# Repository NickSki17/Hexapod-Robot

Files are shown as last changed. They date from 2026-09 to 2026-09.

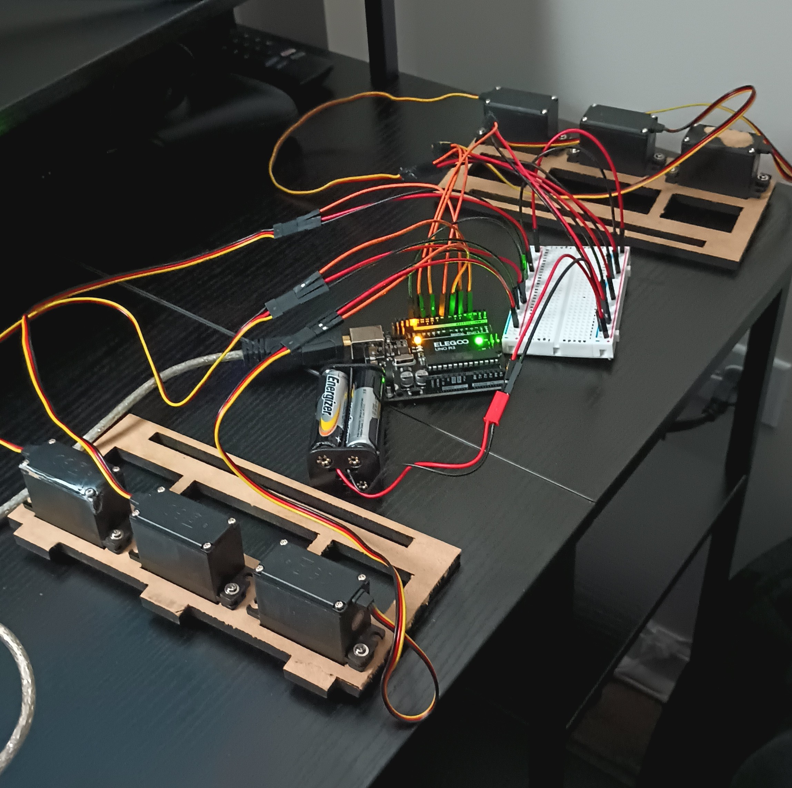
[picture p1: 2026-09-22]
Media/hexapod_wiring.jpg

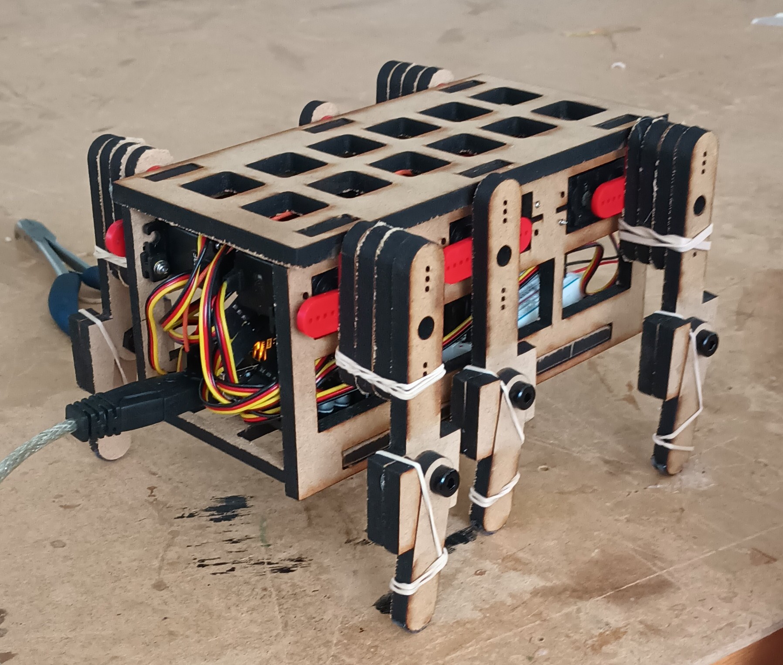
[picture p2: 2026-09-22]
Media/hexapod_front.jpg

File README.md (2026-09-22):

# Hexapod Tripod Gait Robot

A six-legged, ant-inspired robot developed around an alternating tripod gait, passive lower-leg mechanisms, and six servo-driven actuated joints. The project combines concept selection, Inventor CAD, preliminary actuator sizing, Arduino firmware, fabrication, and a physical walking demonstration.

**Tools:** Autodesk Inventor, Arduino C++, `Servo.h`, MDF fabrication

## Project Overview

| **Feature** | **Specification / Detail** | **Evidence Class**  |
| :--- | :--- | :--- |
| **Architecture** | 6-legged hexapod with tripod gait | Designed |
| **Microcontroller** | Arduino Uno | Physical Prototype  |
| **Actuators** | 6 × Hitec HS-425BB standard servos | Physical Prototype  |
| **Chassis Material** | 1/4″ (6.35 mm) MDF | Physical Prototype  |
| **Degrees of Freedom** | 6 total (1 actuated DOF per leg) | Designed |
| **Knee Joints** | Passive mechanical stops (~7.5°) with elastic assist | Designed / Physical |
| **Walking Speed** | Not measured in this repository | Unverified |
| **Power Supply** | 6 V battery pack | Physical Prototype  |

The robot uses six legs arranged into two alternating tripod groups. Each leg features one servo-driven shoulder joint paired with a passive lower-leg mechanism. During stance, a mechanical stop makes the lower leg act as a rigid support member. During swing, the lower linkage folds forward to reduce toe dragging before returning via elastic assist.

### Concept Selection

The hexapod design was selected over an inchworm-inspired alternative based on preliminary design trade-offs:

* **Static Stability:** Provides a three-point support polygon during each tripod phase without requiring active balancing.
* **Mechanical Simplicity:** Uses single-DOF active joints with passive compliant knees to reduce mechanical and control complexity.

## Mechanical Design & Fabrication

The physical robot is constructed from 1/4″ (6.35 mm) MDF for the main chassis, upper legs, and lower legs, with six Hitec HS-425BB servos controlled by an Arduino Uno.

* **Leg Geometry:** Upper leg length: ~60 mm | Lower leg length: 40 mm
* **Body Offset:** Legs offset 26 mm from chassis centerline
* **Knee Joints:** Passive mechanical stops limiting forward rotation to ~7.5°, with elastic return assist
* **Traction:** Rubber toe grips

## Engineering Sizing & Analysis

The preliminary design calculations evaluated the static torque demands on the shoulder servos under simplified load conditions.

| **Parameter** | **Value** | **Evidence Class**  | **Notes / Source** |
| :--- | :--- | :--- | :--- |
| **Calculated Robot Mass** | 0.69 kg | Calculated | Sum of chassis, servos, battery, and leg components |
| **Total Weight ($W$)** | 6.77 N | Calculated | Derived from $0.69\text{ kg} \times 9.81\text{ m/s}^2$ |
| **Assumed Leg Load ($F_{leg}$)** | 3.38 N | Assumed | Load assumption used in original sizing calculation |
| **Required Torque ($T_{req}$)**  | 0.203 N·m (2.07 kgf·cm) | Calculated | Static moment arm check at 60 mm |
| **Servo Stall Torque** | 4.10 kgf·cm | Specified | Hitec HS-425BB datasheet rating at 6 V |
| **Static Factor of Safety** | ~1.98 | Preliminary theoretical calculation | Ratio of rated/stall torque to required static torque under the documented simplified load assumption |
| **Walking Speed** | 0.24 m/s (1.3 BL/s) | Reported benchmark  | Instructor-evaluated physical benchmark |

> **Analysis Note:** Equal static load sharing across an ideal 3-leg tripod stance yields ~2.26 N per leg ($6.77\text{ N}/3$). The 3.38 N value was retained from the original sizing calculation as the documented design load assumption. The ~1.98 factor of safety is therefore a preliminary/theoretical static calculation based on that assumption and the servo's rated/stall torque; it is not an experimentally validated operating margin. These calculations do not model dynamic acceleration, joint friction, or voltage drop under load.

## Control System & Firmware

The control software is implemented in Arduino C++ using the standard `Servo.h` library.

### Servo Pin Assignment

| **Servo Leg Position** | **Arduino Pin** | **Neutral Position** | **Target Stance Angle** |
| :--- | :--- | :--- | :--- |
| **Left Front (LF)** | Pin 2 | 90° | 70° |
| **Left Middle (LM)** | Pin 4 | 90° | 110° |
| **Left Rear (LR)** | Pin 7 | 90° | 68° |
| **Right Front (RF)** | Pin 8 | 90° | 70° |
| **Right Middle (RM)**  | Pin 10 | 90° | 110° |
| **Right Rear (RR)** | Pin 12 | 90° | 67° |

### Gait Execution

1. **Startup:** Attaches all six servos and smoothly transitions from 90° neutral to the initial gait position over 1000 ms.
2. **Stance Hold:** Holds the initial position for 7000 ms.
3. **Tripod Gait:** Alternates between two tripod groups:

   * **Tripod A:** LF, RM, LR
   * **Tripod B:** RF, LM, RR
4. **Smooth Interpolation:** Uses 25 sub-steps over a nominal 225 ms phase to coordinate servo motion.

The current control system is **open-loop** and does not use position feedback or closed-loop gait control.

## Physical Prototype & Media

The physical robot was fabricated, wired, and tested as a walking prototype.

* [Front Profile View](Media/hexapod_front.jpg)
* [Rear Profile View](Media/hexapod_rear.jpg)
* [Chassis & Servo Layout](Media/hexapod_body.jpg)
* [Arduino & Power Wiring](Media/hexapod_wiring.jpg)
* [Walking Video Demonstration](Media/hexapod_walking_demo.mp4)

## Documentation & CAD

* [Arduino Firmware](Code/hexapod_controller.ino)
* [Engineering / Design Analysis](Documentation/hexapod_design_analysis.pdf)
* [Mechanical Drawings](Documentation/hexapod_engineering_drawings.pdf)
* [Inventor Assembly](CAD/hexapod_assembly.iam)
* [Inventor Presentation](CAD/hexapod_presentation.ipn)
* [Inventor Parts](CAD/CAD%20Parts/)

## Limitations & Future Work

* **Open-Loop Control:** No ground-contact, IMU, or position feedback is currently implemented.
* **Dynamic Torque Modeling:** The actuator sizing uses a simplified static moment-arm calculation and does not model dynamic leg loading.
* **Gait Optimization:** Stride amplitude and timing are currently fixed firmware parameters.
* **Quantitative Testing:** The repository does not include an independently documented walking-speed measurement, distance testing, physical mass measurement, or servo calibration data. The 0.24 m/s value in the analysis table is an instructor-evaluated benchmark reported by the project documentation.
* **Firmware Notes:** The gait uses fixed angle, timing, and interpolation parameters; no feedback or automatic gait adaptation is implemented.

## Repository Structure

```text
Hexapod-Robot/
├── README.md
├── .gitignore
├── Code/
│   └── hexapod_controller.ino
├── CAD/
│   ├── hexapod_assembly.iam
│   ├── hexapod_presentation.ipn
│   ├── CAD Parts/
│   └── OldVersions/
├── Documentation/
│   ├── hexapod_design_analysis.pdf
│   └── hexapod_engineering_drawings.pdf
└── Media/
    ├── hexapod_front.jpg
    ├── hexapod_rear.jpg
    ├── hexapod_body.jpg
    ├── hexapod_wiring.jpg
    └── hexapod_walking_demo.mp4
```

## Tools & Skills

**Autodesk Inventor · Arduino C++ · Servo Control · Tripod Gait · Mechanism Design · Actuator Sizing · Static Torque Analysis · CAD · MDF Fabrication · Physical Prototyping**

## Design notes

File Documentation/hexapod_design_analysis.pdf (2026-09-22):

Ant Inspired: Six legs arranged into two groups of three legs to act as a stable tripod. On servo drive each leg. It has a tripod gait where the bottom linkage of the leg is freely moving. When a leg is on the ground pushing, the knee stop locks the shin in place, creating a rigid leg that propels the robot forward. When the leg lifts off the ground, the shin freely folds forward, allowing the leg to swing back compactly through the air without dragging.

Inchworm Inspired: Two body segments that are connected by an extension mechanism. To push forward, the rear anchor will activate, and the front will deactivate. The servo will rotate causing an extension from a crank-rocker linkage. Then the anchors will switch, and the rear will be pulled forward.

I chose the hexapod (ant-inspired) because it offers the best balance of speed, performance, and reliability. The tripod gait provides static stability as there are three legs always supporting the robot, making it unlikely to tip over. Additionally, the hexapod has a potential for higher speed, so it can compete for bonus points. While it requires six servos compared to the inchworms two, the torque analysis confirms the servos have enough torque to move the weight. The bio inspiration is simple and using the crank-rocker linkages as the legs are likely to be successful. Although it requires more servos, the hexapod is the better choice due to its stability and speed.

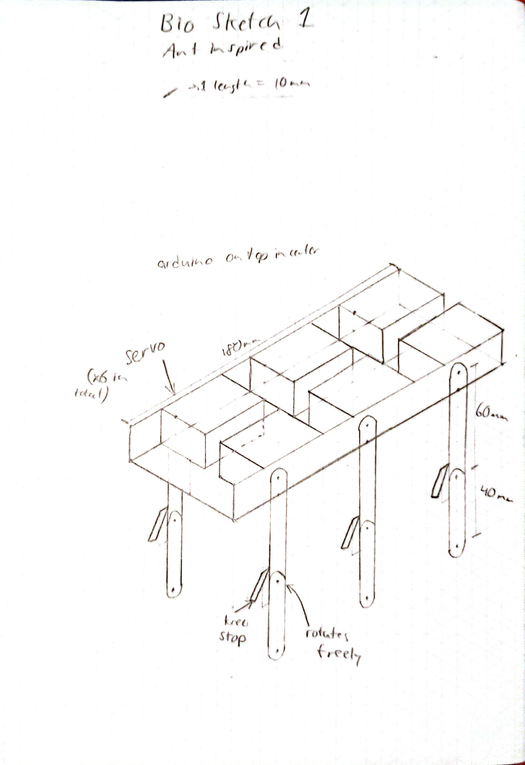
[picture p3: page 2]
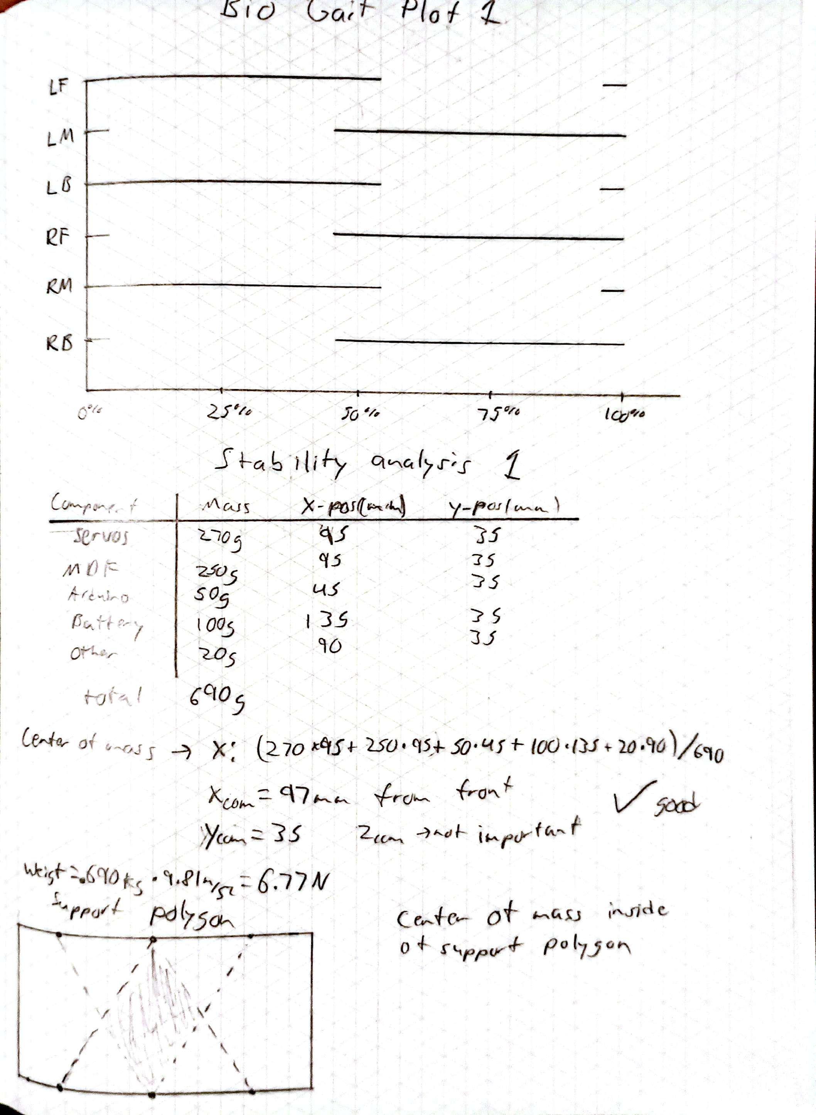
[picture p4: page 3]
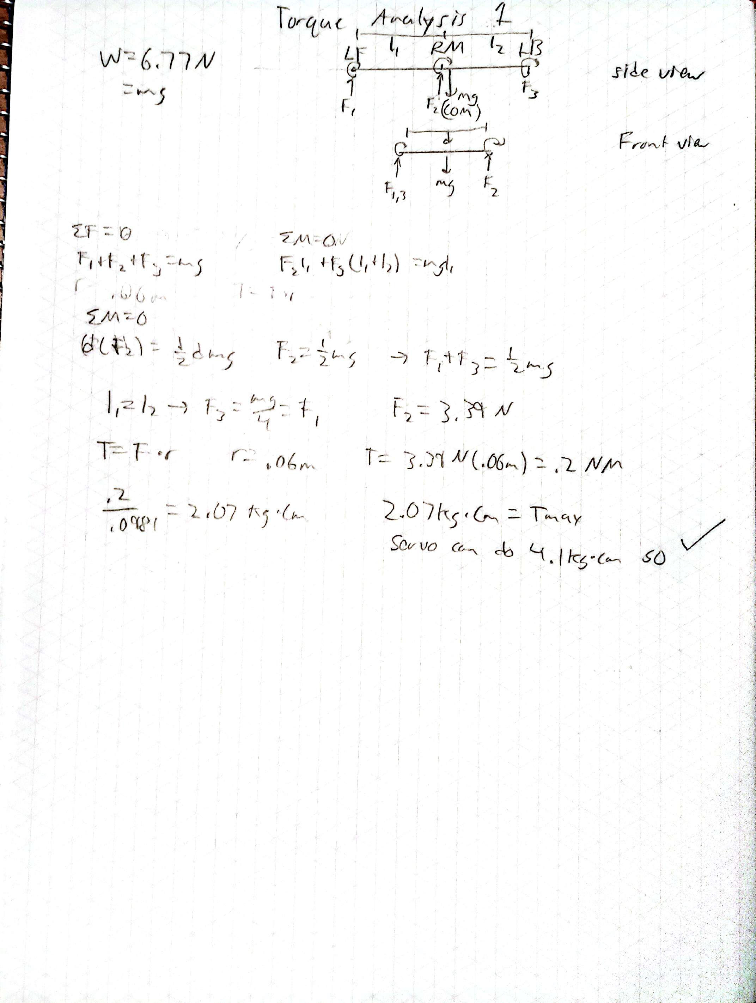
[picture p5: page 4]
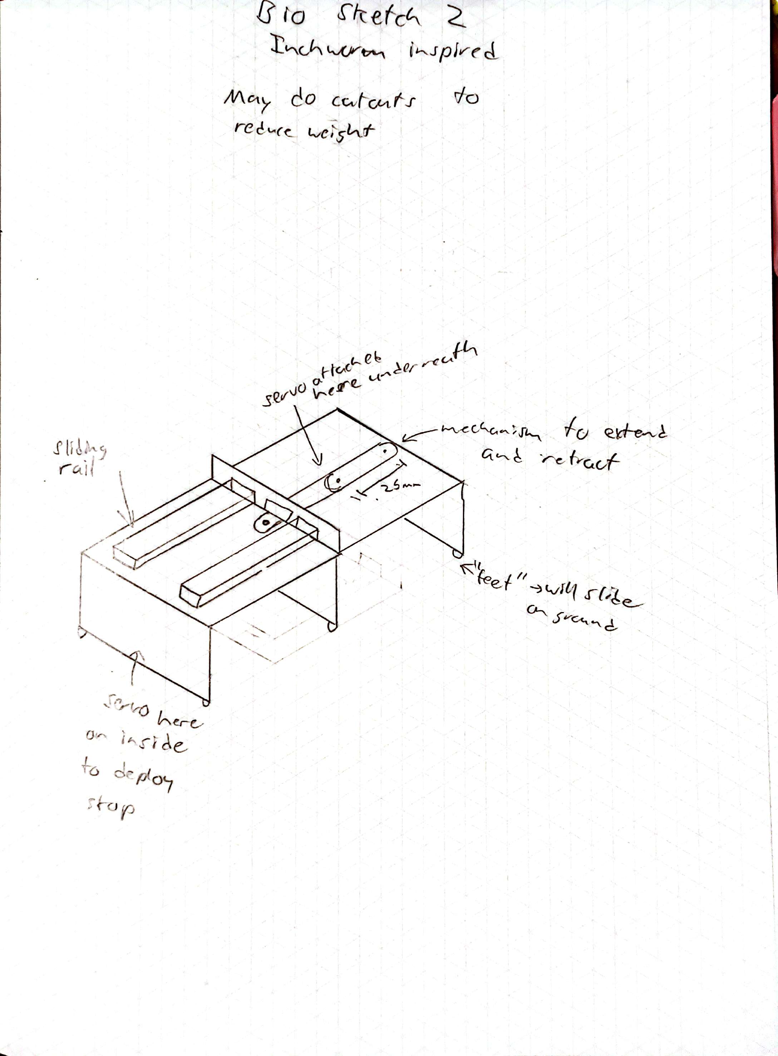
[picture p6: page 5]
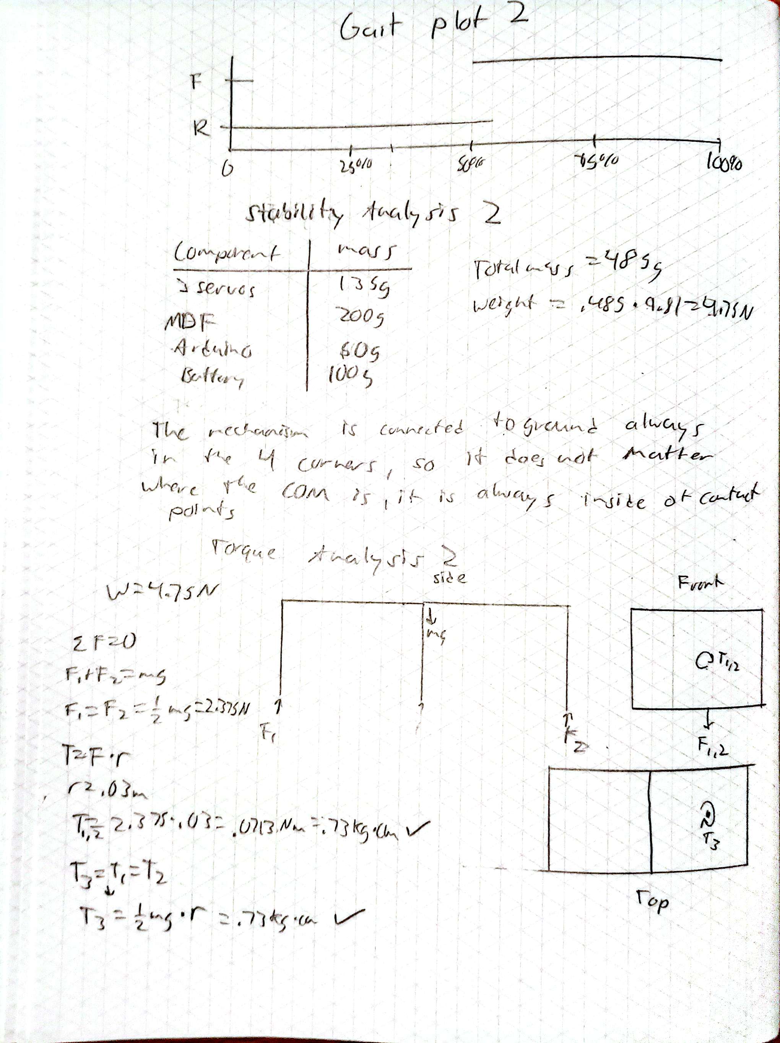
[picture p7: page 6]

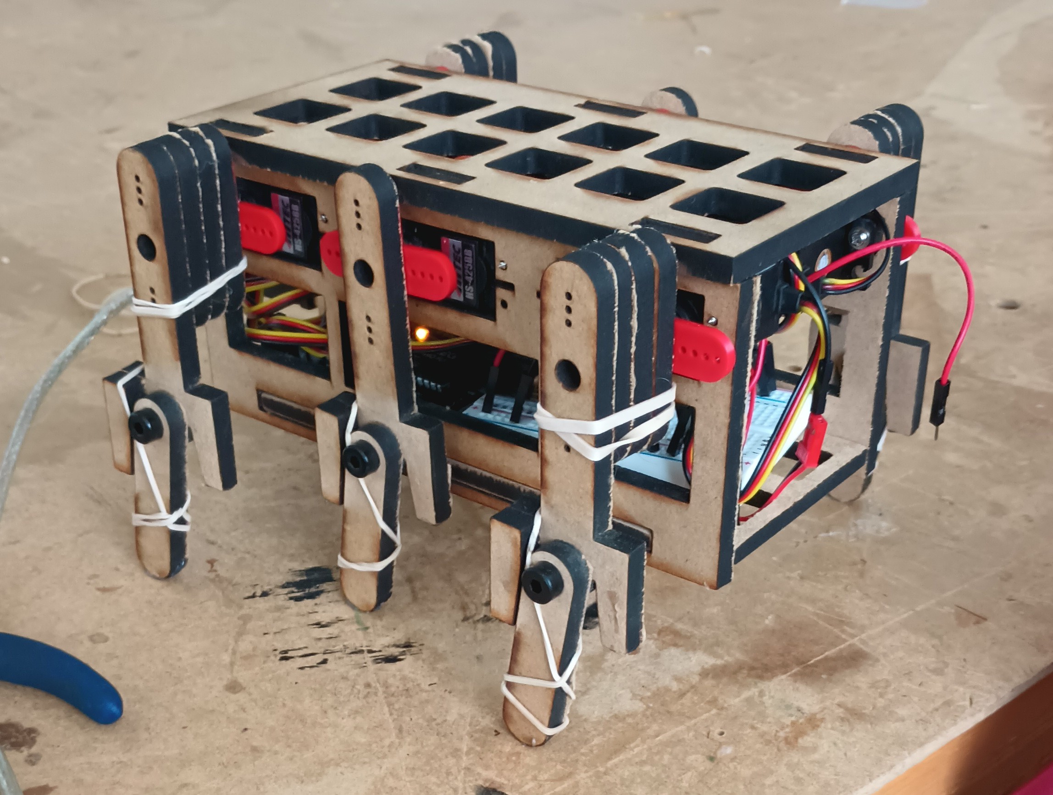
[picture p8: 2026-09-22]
Media/hexapod_rear.jpg

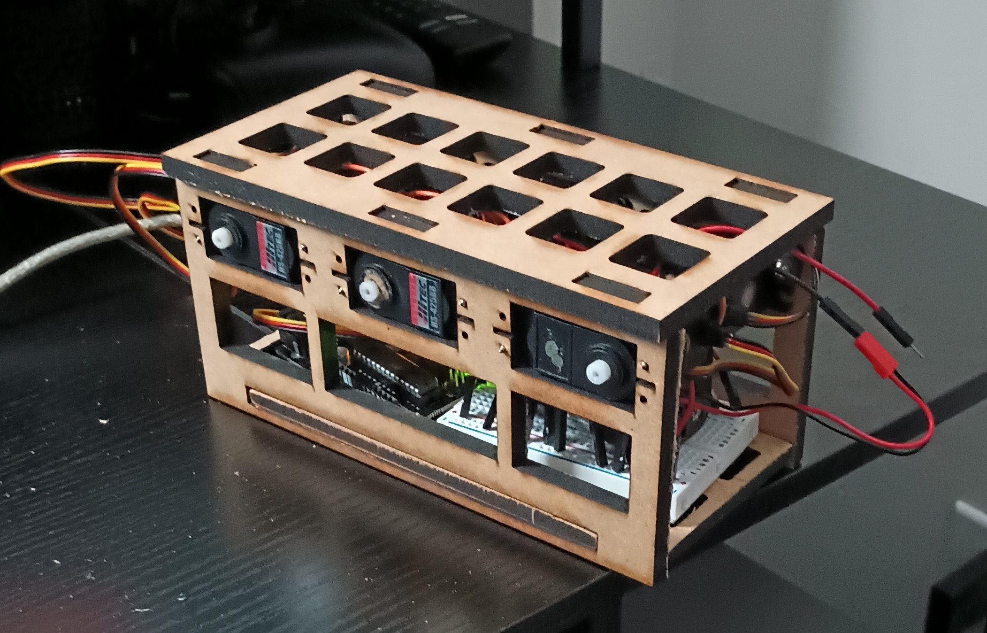
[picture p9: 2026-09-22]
Media/hexapod_body.jpg

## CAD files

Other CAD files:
CAD/CAD Parts/93897A255_Nylon Shoulder Screws (Short Screw) Skiba.ipt
CAD/CAD Parts/Base-Skiba.ipt
CAD/CAD Parts/Bio Servo Skiba.ipt
CAD/CAD Parts/Bio Servo Skiba_MIR1.ipt
CAD/CAD Parts/Lower Leg Skiba.ipt
CAD/CAD Parts/OldVersions/93897A255_Nylon Shoulder Screws (Short Screw) Skiba.0002.ipt
CAD/CAD Parts/OldVersions/Base-Skiba.0007.ipt
CAD/CAD Parts/OldVersions/Bio Servo Skiba.0001.ipt
CAD/CAD Parts/OldVersions/Bio Servo Skiba_MIR1.0002.ipt
CAD/CAD Parts/OldVersions/Lower Leg Skiba.0005.ipt
CAD/CAD Parts/OldVersions/Roof Skiba.0002.ipt
CAD/CAD Parts/OldVersions/Servo Holder Skiba.0001.ipt
CAD/CAD Parts/OldVersions/Servo Horn Skiba.0002.ipt
CAD/CAD Parts/OldVersions/Servo Wall Skiba.0005.ipt
CAD/CAD Parts/OldVersions/Servo Wall Skiba_MIR1.0002.ipt
CAD/CAD Parts/OldVersions/Spacer Skiba.0005.ipt
CAD/CAD Parts/OldVersions/Stop Skiba.0005.ipt
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

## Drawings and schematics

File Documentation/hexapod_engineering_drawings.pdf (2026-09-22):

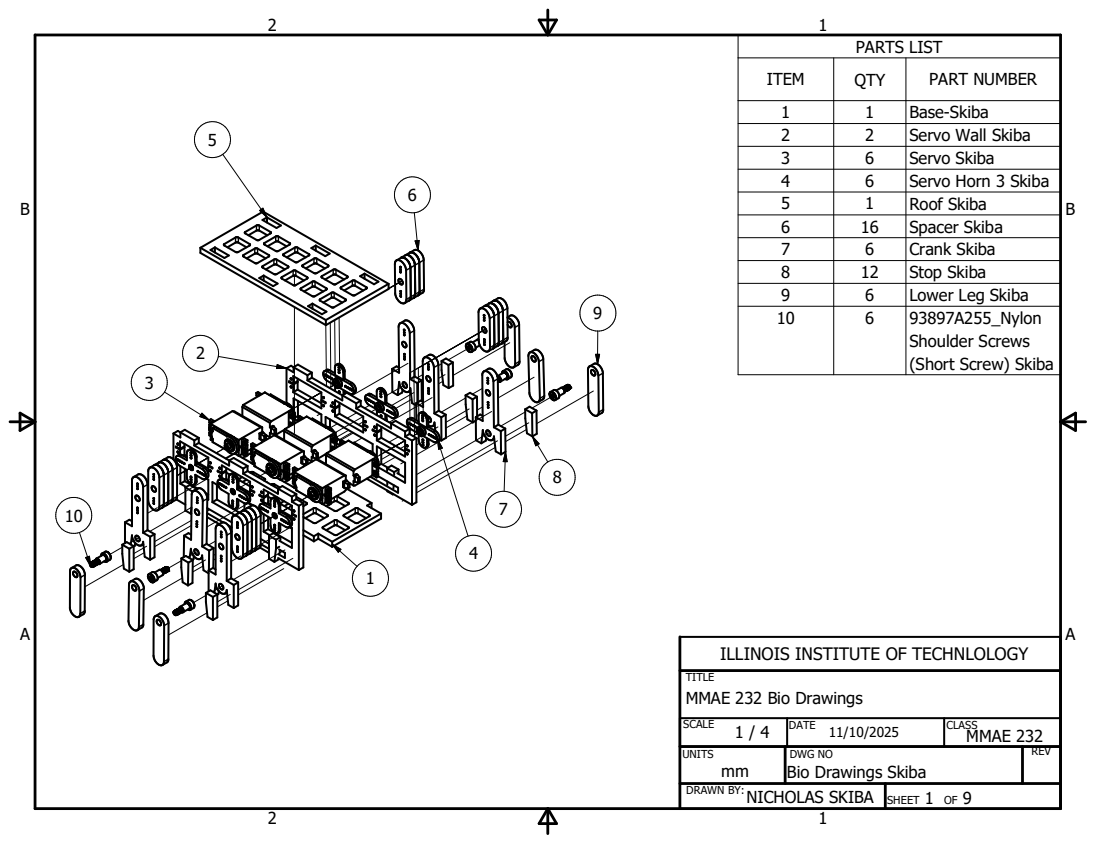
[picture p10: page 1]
REV; SCALE; 1 / 4 DATE; CLASS; MMAE 232; UNITS; DWG NO; PARTS LIST; ITEM; QTY; PART NUMBER; Base-Skiba; Servo Wall Skiba; Servo Skiba; Servo Horn 3 Skiba; Roof Skiba; Spacer Skiba; Crank Skiba; Stop Skiba; Lower Leg Skiba

93897A255_Nylon
Shoulder Screws
(Short Screw) Skiba

ILLINOIS INSTITUTE OF TECHNLOLOGY

TITLE
MMAE 232 Bio Drawings

SHEET 1 OF 9 DRAWN BY:NICHOLAS SKIBA

Bio Drawings Skiba

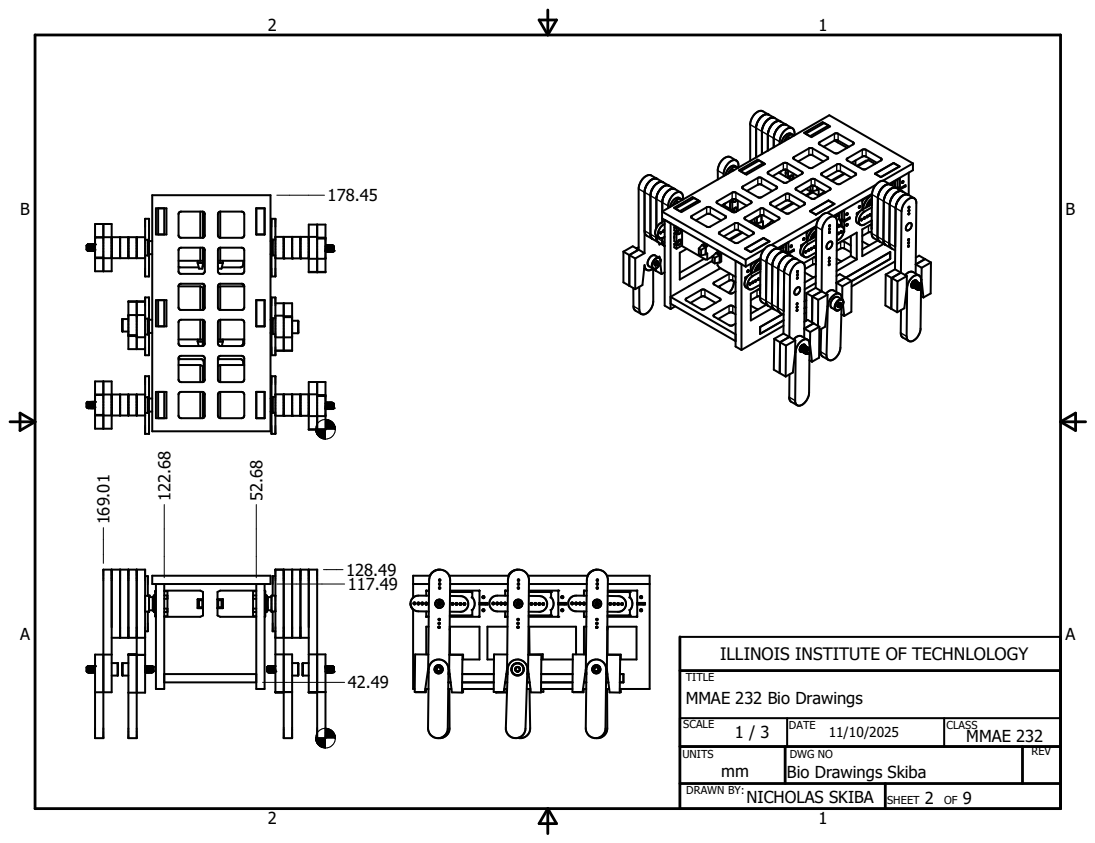
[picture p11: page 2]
REV; SCALE; 1 / 3 DATE; CLASS; MMAE 232; UNITS; DWG NO; 117.49 ¹²².68; 128.49 ¹⁶⁹.01

ILLINOIS INSTITUTE OF TECHNLOLOGY

TITLE
MMAE 232 Bio Drawings

SHEET 2 OF 9 DRAWN BY:NICHOLAS SKIBA

Bio Drawings Skiba

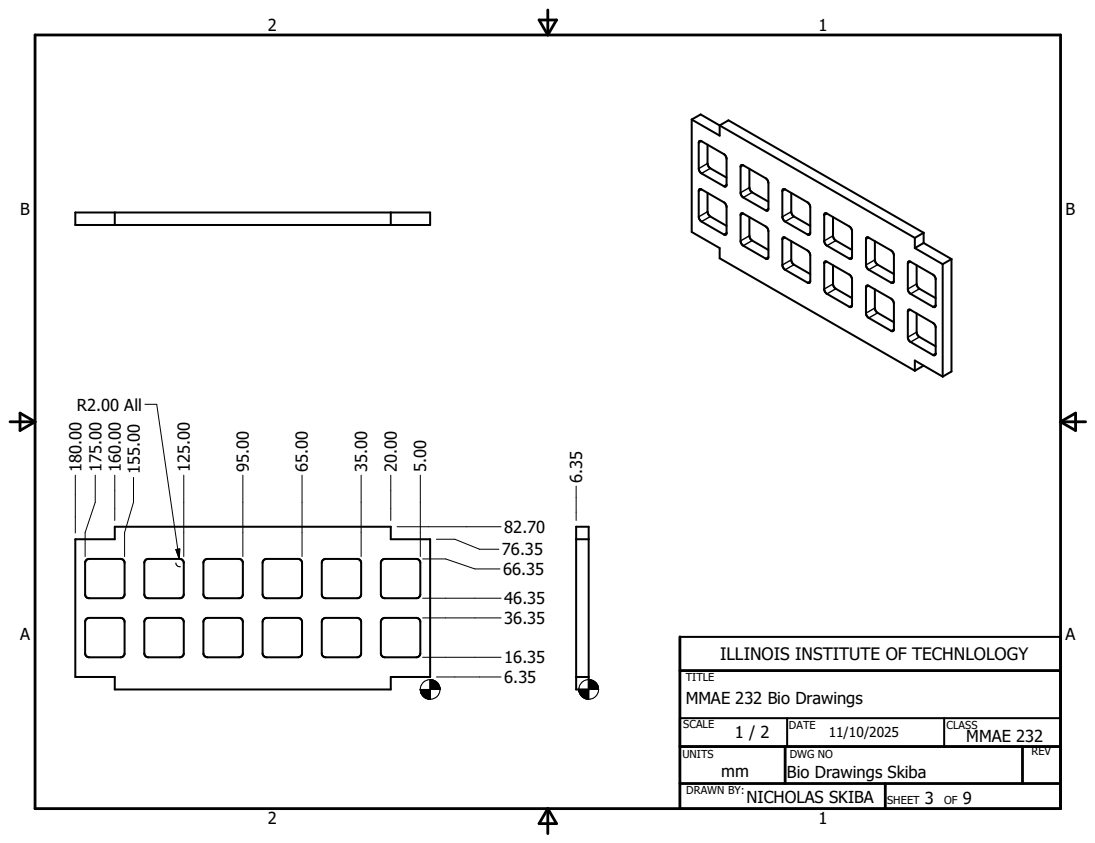
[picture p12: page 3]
82.70 ¹⁸⁰.00 175.00 160.00 155.00; R2.00 All

ILLINOIS INSTITUTE OF TECHNLOLOGY

TITLE
MMAE 232 Bio Drawings

SCALE 1 / 2 | DATE 11/10/2025 | CLASS MMAE 232
UNITS mm | DWG NO Bio Drawings Skiba | REV

SHEET 3 OF 9 DRAWN BY:NICHOLAS SKIBA

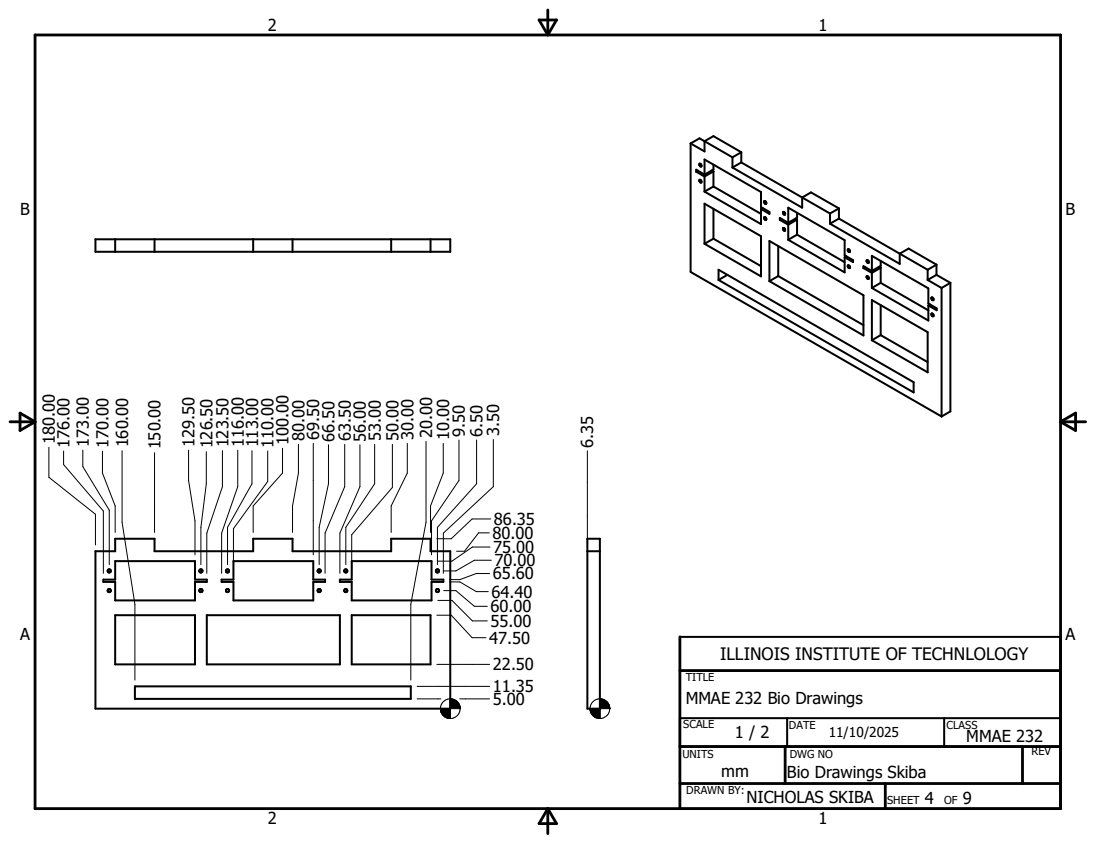
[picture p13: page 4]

ILLINOIS INSTITUTE OF TECHNLOLOGY

TITLE
MMAE 232 Bio Drawings

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

SHEET 4 OF 9 DRAWN BY:NICHOLAS SKIBA

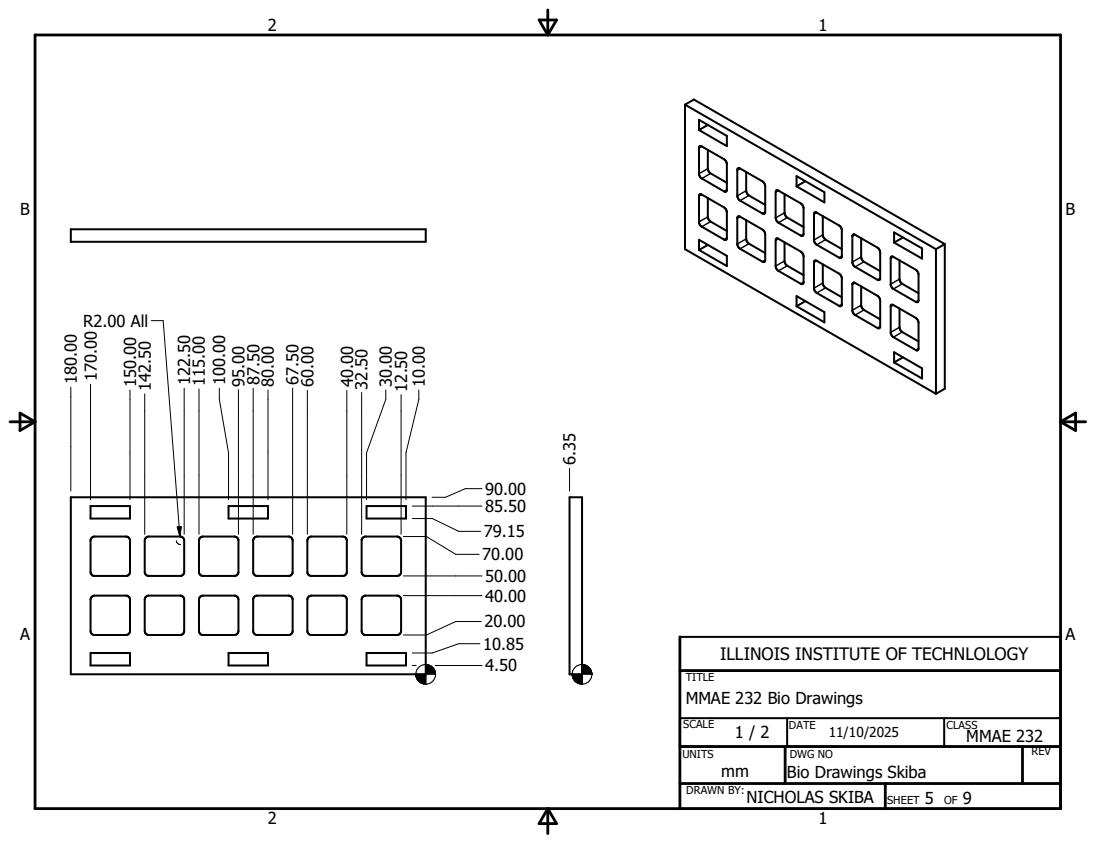
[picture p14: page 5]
R2.00 All

ILLINOIS INSTITUTE OF TECHNLOLOGY

TITLE
MMAE 232 Bio Drawings

SCALE 1 / 2 | DATE 11/10/2025 | CLASS MMAE 232
UNITS | DWG NO Bio Drawings Skiba | REV

SHEET 5 OF 9 DRAWN BY:NICHOLAS SKIBA

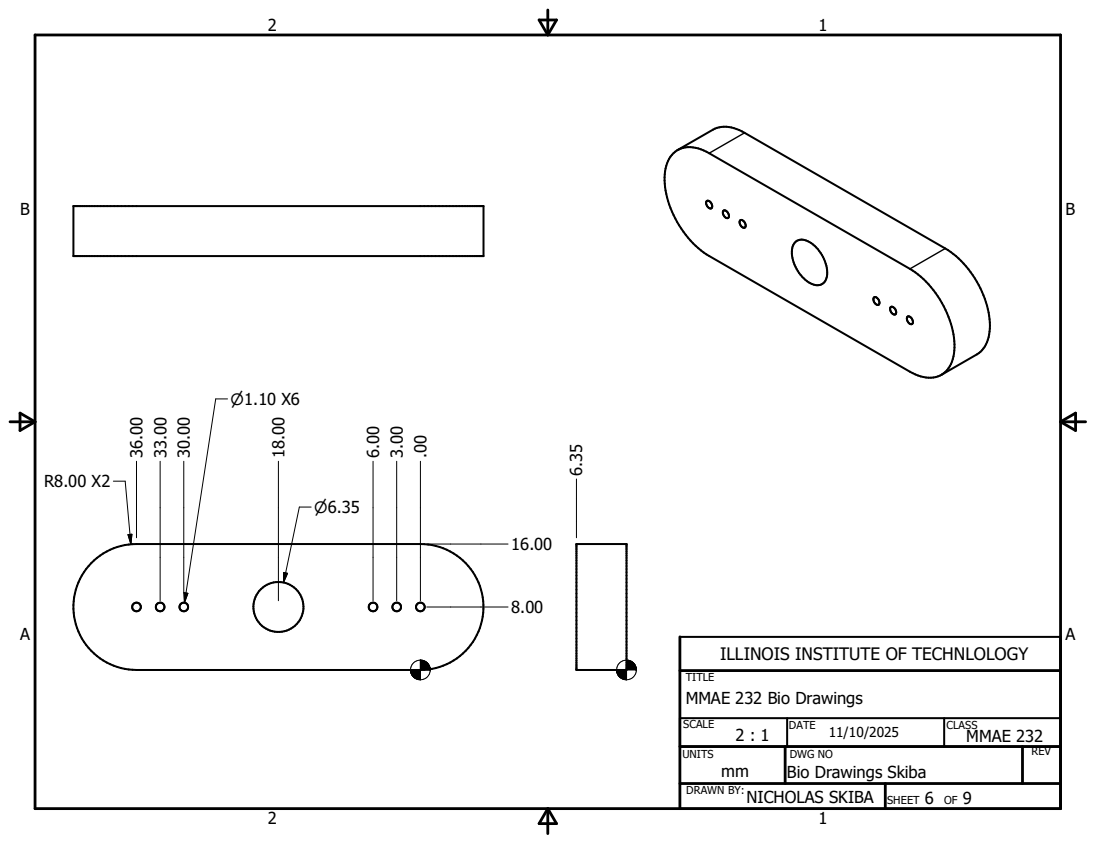
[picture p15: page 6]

ILLINOIS INSTITUTE OF TECHNLOLOGY

TITLE
MMAE 232 Bio Drawings

SCALE 2 : 1 | DATE 11/10/2025 | CLASS MMAE 232
UNITS | DWG NO Bio Drawings Skiba | REV

SHEET 6 OF 9 DRAWN BY:NICHOLAS SKIBA

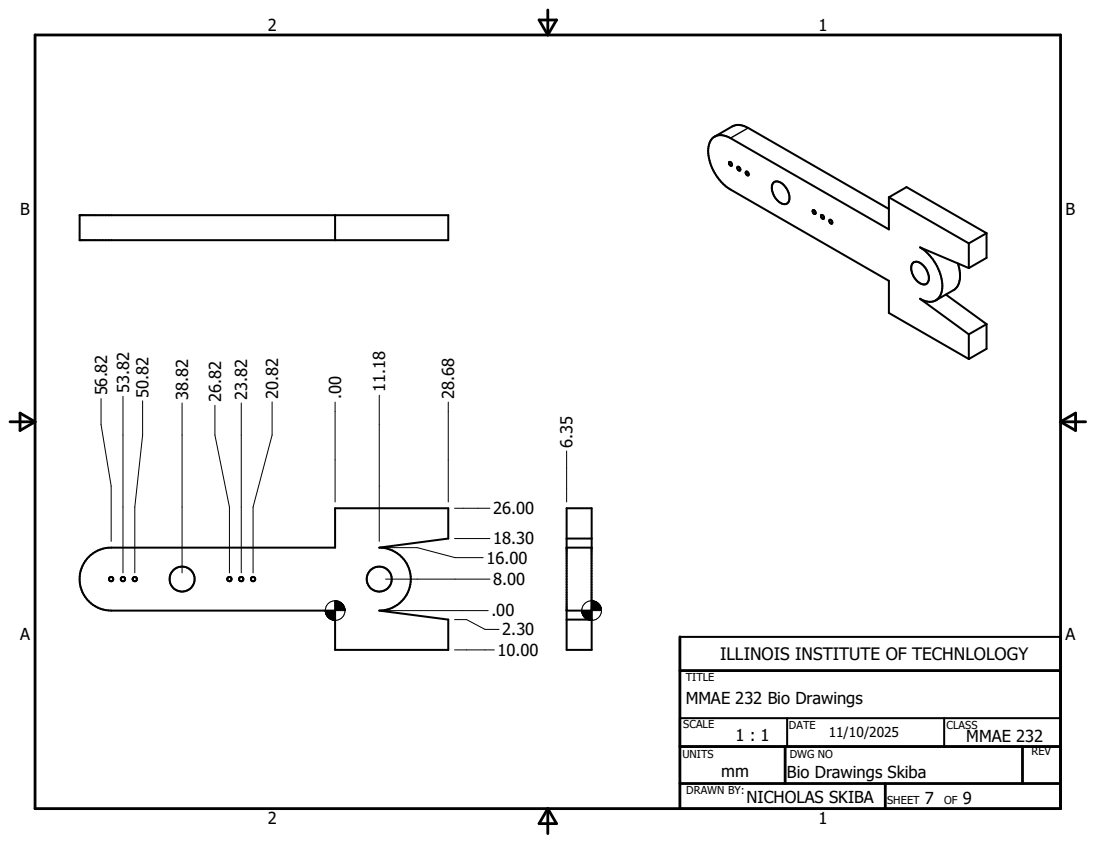
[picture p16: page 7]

ILLINOIS INSTITUTE OF TECHNLOLOGY

TITLE
MMAE 232 Bio Drawings

SCALE 1 : 1 | DATE 11/10/2025 | CLASS MMAE 232
UNITS | DWG NO Bio Drawings Skiba | REV

SHEET 7 OF 9 DRAWN BY:NICHOLAS SKIBA

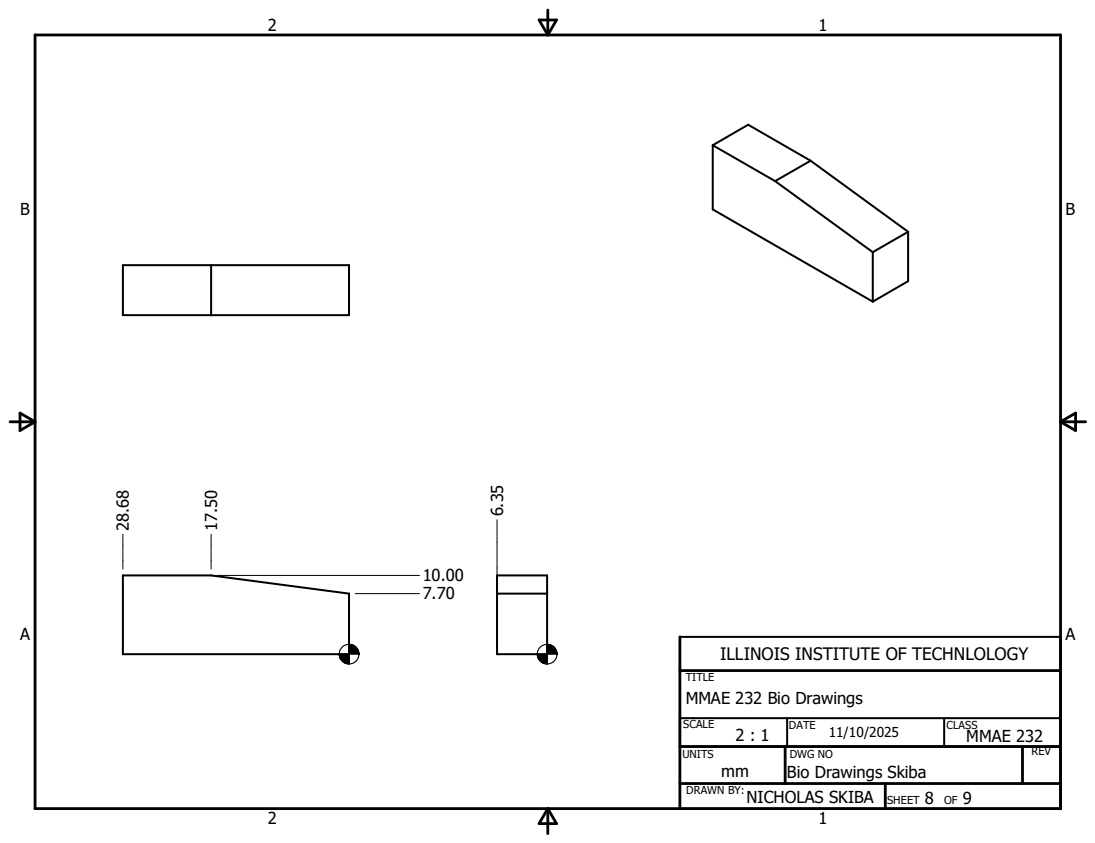
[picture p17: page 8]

ILLINOIS INSTITUTE OF TECHNLOLOGY

TITLE
MMAE 232 Bio Drawings

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

SHEET 8 OF 9 DRAWN BY:NICHOLAS SKIBA

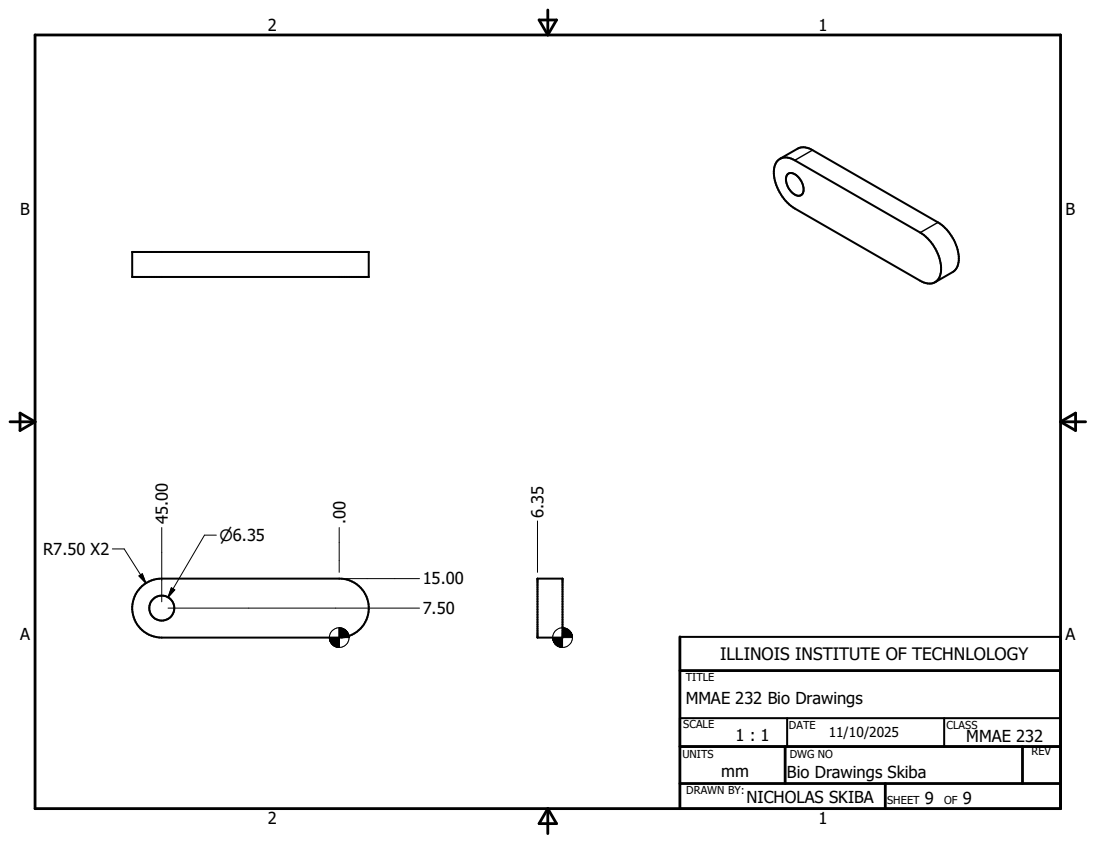
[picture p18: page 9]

ILLINOIS INSTITUTE OF TECHNLOLOGY

TITLE
MMAE 232 Bio Drawings

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

SHEET 9 OF 9 DRAWN BY:NICHOLAS SKIBA

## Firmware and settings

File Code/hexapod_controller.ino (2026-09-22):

#include <Servo.h>

// ────────────────────────────────────────────────
// SERVO PIN ASSIGNMENTS
// ────────────────────────────────────────────────
const int LF_PIN = 2;
const int LM_PIN = 4;
const int LR_PIN = 7;
const int RF_PIN = 8;
const int RM_PIN = 10;
const int RR_PIN = 12;

// ────────────────────────────────────────────────
// SERVO OBJECTS
// ────────────────────────────────────────────────
Servo servoLF;
Servo servoLM;
Servo servoLR;
Servo servoRF;
Servo servoRM;
Servo servoRR;

// ────────────────────────────────────────────────
// CALIBRATION
// ────────────────────────────────────────────────
int neutralAngles[6] = { 90, 90, 90, 90, 90, 90 };  // LF, LM, LR, RF, RM, RR

int endGaitAngles[6] = { 70, 110, 68, 70, 110, 67 };

int servoDirection[6] = { 1, 1, 1, 1, 1, 1 };

const int STEP_TIME = 225;
const int SMOOTH_STEPS = 25;
int currentAngles[6];

// ────────────────────────────────────────────────
// HELPER FUNCTIONS
// ────────────────────────────────────────────────
int constrainAngle(int angle) {
  if (angle < 0) return 0;
  if (angle > 180) return 180;
  return angle;
}

void writeServoSafe(int servoIndex, int angle) {
  int neutral = neutralAngles[servoIndex];
  int offset = angle - neutral;
  offset *= servoDirection[servoIndex];
  angle = neutral + offset;

  angle = constrainAngle(angle);
  currentAngles[servoIndex] = angle;

  switch (servoIndex) {
    case 0: servoLF.write(angle); break;
    case 1: servoLM.write(angle); break;
    case 2: servoLR.write(angle); break;
    case 3: servoRF.write(angle); break;
    case 4: servoRM.write(angle); break;
    case 5: servoRR.write(angle); break;
  }
}

void setAllServosSmooth(int targetAngles[], int duration) {
  int startAngles[6];
  for (int i = 0; i < 6; i++) startAngles[i] = currentAngles[i];

  int steps = duration / 20;
  if (steps < 1) steps = 1;

  for (int step = 1; step <= steps; step++) {
    for (int i = 0; i < 6; i++) {
      int angle = startAngles[i] + ((targetAngles[i] - startAngles[i]) * step) / steps;
      writeServoSafe(i, angle);
    }
    delay(20);
  }
}

// ────────────────────────────────────────────────
// SETUP
// ────────────────────────────────────────────────
void setup() {
  Serial.begin(9600);
  Serial.println();
  Serial.println("════════ HEXAPOD ANT ROBOT - START ════════");
  Serial.println();

  delay(2000);

  servoLF.attach(LF_PIN);
  servoLM.attach(LM_PIN);
  servoLR.attach(LR_PIN);
  servoRF.attach(RF_PIN);
  servoRM.attach(RM_PIN);
  servoRR.attach(RR_PIN);

  // 1. Initialize current angles to 0 before smooth move
  for (int i = 0; i < 6; i++) currentAngles[i] = 0;

  // 2. Move all servos smoothly to the calculated end-gait position
  Serial.print("Moving to End-Gait Position: {");
  for (int i = 0; i < 6; i++) {
    Serial.print(endGaitAngles[i]);
    if (i < 5) Serial.print(", ");
  }
  Serial.println("}");
  setAllServosSmooth(endGaitAngles, 1000);  // 1 second smooth transition

  // 3. Hold the end-gait position for approximately 7 seconds
  Serial.println("✓ All systems ready! Holding position for 7 seconds...");
  delay(7000);
  Serial.println("Starting continuous walk.");
}

// ────────────────────────────────────────────────
// TRIPOD GAIT
// ────────────────────────────────────────────────
void tripodStepContinuous() {

  // Tripod A (LF, RM, LR) Extremes
  int LF_start = neutralAngles[0] + 20;
  int LF_end = neutralAngles[0] - 20;
  int RM_start = neutralAngles[4] - 21;
  int RM_end = neutralAngles[4] + 20;
  int LR_start = neutralAngles[2] + 22;
  int LR_end = neutralAngles[2] - 22;

  // Tripod B (RF, RR, LM) Extremes
  int RF_start = neutralAngles[3] + 20;
  int RF_end = neutralAngles[3] - 20;
  int RR_start = neutralAngles[5] + 20;
  int RR_end = neutralAngles[5] - 23;
  int LM_start = neutralAngles[1] - 20;
  int LM_end = neutralAngles[1] + 20;

  const int steps = SMOOTH_STEPS;

  // Phase 2 (Starts first since we initialized to the end-of-Phase-1 position)
  // Tripod B (Stance/Push) SLOW, Tripod A (Swing/Return) FAST
  for (int step = 0; step <= steps; step++) {
    float tSlow = (float)step / steps;
    float tFast = (float)step / (steps / 4.0);
    if (tFast > 1.0) tFast = 1.0;

    // Tripod B - SLOW push (Stance phase)
    int angleRF = RF_end + tSlow * (RF_start - RF_end);
    int angleRR = RR_end + tSlow * (RR_start - RR_end);
    int angleLM = LM_end + tSlow * (LM_start - LM_end);

    writeServoSafe(3, angleRF);  // RF
    writeServoSafe(5, angleRR);  // RR
    writeServoSafe(1, angleLM);  // LM

    // Tripod A - FAST return (Swing phase)
    int angleLF = LF_end + tFast * (LF_start - LF_end);
    int angleRM = RM_end + tFast * (RM_start - RM_end);
    int angleLR = LR_end + tFast * (LR_start - LR_end);

    writeServoSafe(0, angleLF);  // LF
    writeServoSafe(4, angleRM);  // RM
    writeServoSafe(2, angleLR);  // LR

    delay(STEP_TIME / steps);
  }

  // Phase 1
  // Tripod A (Stance/Push) SLOW, Tripod B (Swing/Return) FAST
  for (int step = 0; step <= steps; step++) {
    float tSlow = (float)step / steps;
    float tFast = (float)step / (steps / 4.0);
    if (tFast > 1.0) tFast = 1.0;

    // Tripod A - SLOW push (Stance phase)
    int angleLF = LF_start + tSlow * (LF_end - LF_start);
    int angleRM = RM_start + tSlow * (RM_end - RM_start);
    int angleLR = LR_start + tSlow * (LR_end - LR_start);

    writeServoSafe(0, angleLF);  // LF
    writeServoSafe(4, angleRM);  // RM
    writeServoSafe(2, angleLR);  // LR

    // Tripod B - FAST return (Swing phase)
    int angleRF = RF_start + tFast * (RF_end - RF_start);
    int angleRR = RR_start + tFast * (RR_end - RR_start);
    int angleLM = LM_start + tFast * (LM_end - LM_start);

    writeServoSafe(3, angleRF);  // RF
    writeServoSafe(5, angleRR);  // RR
    writeServoSafe(1, angleLM);  // LM

    delay(STEP_TIME / steps);
  }
}

// ────────────────────────────────────────────────
// MAIN LOOP
// ────────────────────────────────────────────────
void loop() {
  // Continuous loop after the 10-second pause in setup
  tripodStepContinuous();
}
